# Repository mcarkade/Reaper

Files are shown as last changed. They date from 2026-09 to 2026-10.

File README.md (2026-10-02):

# Reaper

**Current shop jobs: [four smaller sequential DXFs](Plywood/Batches/README.md).** Cut those four OR the full master once, never both. Their part geometry is identical.
**[Open the complete R5G beginner assembly guide](Reaper_Beginner_Assembly_R5G.pdf).** Use its part atlas, illustrated fitting and assembly sequence, wiring, configuration and physical acceptance gates.

| Find | Current location |
|---|---|
| All 37 plywood pieces, one combined cutting file | [R5G DXF](Plywood/Reaper_ALL_PLYWOOD_R5G_6mm_PROVISIONAL.dxf) and [cutting instructions](Plywood/README.md) |
| Part quantities and stock-panel positions | [Parts.csv](Data/Parts.csv), [panel map](Plywood/PART_TO_PANEL.csv) |
| Missed unchanged A23/A36/HTRB STLs | [Print/Individual](Print/Individual), [print instructions](Print/README.md) |
| Current finished CAD and laser stock | [CAD](CAD), [wood fitting details](Data/Wood_Assembly_Datums.md) |
| Existing foam cutting files | [Foam](Foam) |
| Wiring and remaining acceptance checks | [Wiring](Illustrations/Complete_Wiring.svg), [physical checks](Data/Physical_Checks.csv) |

The current requested cutting set contains 37 nominal 6 mm plywood pieces including A26 and reinforced A44_L/R. A26 has no motor screw holes; verify the real motor and complete mount fit before hand marking/drilling. This cutting file includes A18's requested 0.5 mm total upper receiver allowance, strengthened A01 profiles and the shortened A62_A stock. A43 face rebates and A44 underside paring remain secondary operations shown in the guide; the laser cannot make them.

The geometry/layout is digitally checked. Actual stock thickness, kerf, printed receiver batch, physical insertion, screw engagement, adhesive quality and loaded performance remain qualification checks. The earlier R5F PDF, old wood jobs and printed A26/A44 fit prototypes are archived references; use the R5G guide and cutting set for the current job. Existing foam and unrelated prints are retained. Most parts are already printed; do not reprint them automatically.

Landing gear is deferred until after midsems; DARTS registration is pending. The 20%-chord CG is a geometric starting point. CAD or bench checks do not establish flight readiness.

[Original CAD model](https://cad.onshape.com/documents/da0c1a9f98b6358f736153b1/w/040544fbf77b8cf6608e2eb9/e/28c526eeb45b3f50fa69269f) Â· [Source build video](https://www.youtube.com/watch?v=X-Q08HQq7fM)

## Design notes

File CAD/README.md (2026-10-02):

# Current CAD

Reaper_R5_Assembly.step is the named R5G assembly: 66 original part identities plus two preserved whole carbon rods. Parts contains finished world-coordinate geometry; Stock_Blanks contains distinct laser stock; Secondary_Removal contains local finishing tools. A26 and A44 are current plywood parts. Earlier printed fit geometry is preserved in Archive_Fit_Prototypes, and obsolete secondary operations in Archive_Secondary_R5F.

Native assembled foil/skin IDs differ from the FW manufacturing-wrap IDs. N1 is an owned printed nose reference without a corresponding native part in this source set; no mapping is invented. Accepted source foam skins are unchanged reference geometry: the guide requires local internal relief against reinforced A44 and actual board thickness. Raw topology, a clean compound or a printable mesh does not prove physical fit, insertion, retention, material strength or flight readiness.

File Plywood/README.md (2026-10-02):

# Current plywood cutting job

**Current shop jobs: [four smaller sequential DXFs](Batches/README.md).** Cut all four once OR the full master once, never both. Their part geometry is identical.
[Reaper_ALL_PLYWOOD_R5G_6mm_PROVISIONAL.dxf](Reaper_ALL_PLYWOOD_R5G_6mm_PROVISIONAL.dxf) contains all 37 aircraft pieces, one of each listed ID, across two 609.6 Ã— 457.2 mm stock layouts. [Layout image](Maps/ALL_PLYWOOD_R5G_Layout.png), [part map](PART_TO_PANEL.csv) and [manufacturing map](Manufacturing_Map.json) identify the pieces. Individual DXFs are the same profiles used in the combined file, for reference; do not cut a second set.

Use nominal 6 mm plywood, millimetres, 100% scale and CUT only. Keep stock face grain along each panel's +X/long direction. A18 is intentionally rotated 90 degrees in this layout to carry its physical grain correctly. Reference stock borders and labels must not cut. Each layout is a separate stock sheet; panel 2 starts at X659.6 mm in the combined file. Nominal minimum part gap is 5 mm; geometric serialization differs by under 0.000004 mm. The shop must measure actual kerf, thickness and machine limits before cutting; no kerf offset is encoded.

All digital profiles and nominal extrusions passed independent readback, source-profile comparison, overlap/spacing, grain and quantity checks. Physical fit and strength are unverified. Qualify representative coupons and dry-fit the actual printed A12 receiver and wood interfaces before committing the complete cutting run.

A43 shallow seats, A62_F's A54 seat, spar seating relief and other existing source secondary operations do not come from laser through-cutting. Follow the guide and [wood datums](../Data/Wood_Assembly_Datums.md). A44's stock-only underside tail allowance must be pared to the finished profile, preserving its full tip and A53 bond area. [Reference paring profiles](Paring_Templates) are explicitly not laser jobs.

Old separate R5F panel files and maps in Archive_R5F are superseded. The current cutting entry is the single R5G combined DXF above.

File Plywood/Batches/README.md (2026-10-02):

# Four sequential cutting jobs

Cut batches01,02,03,04 once each: 9+9+9+10=37 complete pieces. They are translation-only derivatives of the unchanged full R5G master; no part is cropped, rotated or rescaled. All81 closed CUT contours are preserved exactly once. Do not also cut the full master or individual profiles.

Each nominal stock layout is609.6 x228.6mm, grain along X, with10mm margins and5mm part gaps. Cut in millimetres at100%scale, CUT only; reference borders and labels do not cut. These four half-panel layouts occupy the same total stock area as the two original609.6 x457.2mm sheets, before real handling/kerf considerations. Keep material grain and safe stock support. The shop must confirm actual bed size, stock thickness and kerf coupon. Largest individual part A13 is550.6602 x95.64445mm and remains intact; do not scale it to fit a smaller machine.

PART_TO_BATCH.csv and FOUR_BATCHES_Layout.png identify each batch. BATCH_MAP.json records unchanged-master identity and exact translations. The full combined file in the parent directory remains a reference/alternative layout. Guide instructions and secondary fitting are unchanged, including A43 shallow rebates, A44 tail underside paring and A26 physical mount fit/manual motor drilling.

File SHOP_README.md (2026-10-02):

# Workshop files

**Current shop jobs: [four smaller sequential DXFs](Plywood/Batches/README.md).** Cut those four OR the full master once, never both. Their part geometry is identical.
Use the [R5G complete guide](Reaper_Beginner_Assembly_R5G.pdf), [part list](Data/Parts.csv) and [current combined plywood DXF](Plywood/Reaper_ALL_PLYWOOD_R5G_6mm_PROVISIONAL.dxf). All 37 plywood quantities are included across two stock layouts in one file. The older panel jobs in Plywood/Archive_R5F are superseded references.

Measure actual plywood thickness and laser kerf and qualify mating coupons before the full job. Nominal stock is 6 mm, each stock layout is 609.6 Ã— 457.2 mm, and its long X direction is the required face-grain direction. Use millimetres, 100% scale, CUT only. Disable REFERENCE_NOT_CUT and LABELS_NOT_CUT. Select one stock layout at a time unless the bed accepts both; the file spans 1269.2 mm and does not represent one physical sheet. No kerf compensation is encoded.

A18 already includes 0.25 mm per opposed upper receiver-facing edge; do not add that allowance again. Stock remains 6 mm. A43 keeps full-thickness surrounding material and requires only the illustrated local face rebates. A44 stock includes a 3 mm underside tail web: pare the exact sacrificial allowance to the finished taper without shortening the tip before bonding A53. The old A44 trailing-tip trim is superseded. A26 has no motor screw holes and needs real-hardware marking after the physical frame dry-fit. A62_A's old 13.015 mm aft trim is incorporated into the cut length; do not repeat it.

The missed unchanged prints are A23, A36 and HTRB, one each. Use [Print/README.md](Print/README.md); PLA is available, while the source reference recipes specify PLA+. Neither a filename nor a slicer recipe establishes loaded strength. Preserve already completed unrelated prints and foam. Landing-gear hardware remains a later stage.

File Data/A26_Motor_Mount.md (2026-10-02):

# A26 motor mount

Current R5G is nominal 6 mm plywood with no motor screw holes, as requested for actual-motor hand marking. The shaft relief and source axis at X0/Z-2.5 mm are retained; nominal keel/side receiving regions are 6 mm. A26 is included in the single combined plywood file. The earlier square-pattern plate and printed fit prototypes are superseded references.

The documented motor is EMAX ECO II 2807 1300KV. Its [manufacturer drawing](EMAX_ECOII_2807_Manufacturer_Drawing.jpg) specifies four M3 mounting holes on a 19 mm diameter bolt circle: adjacent centres are 13.435 mm, not a 19 mm square. Align the real motor and mark the pattern only after the complete A26/A43/A62_A/printed-tail dry-fit proves seating, assembly order and tool access. The current DXF deliberately has zero motor screw holes; the centre shaft relief is not a mounting hole.

The frame joint is chiefly the forward-face bond and keel seat; do not mistake the plate's flank recesses for fully captured load-bearing tongues. Proof the real attachment and load path. Digital installed interference and sampled aft insertion checks passed, while a vertical drop is blocked. They do not establish the actual plywood fit or bonding strength. User-reported incorrect physical frame fit remains a physical acceptance gate until this exact replacement is dry-fitted.

A62_A's current stock length is 482.650 mm, flush at Y582.650. Its old 13.015 mm aft projection has already been removed in the current cutting profile: do not trim a further 13.015 mm.

Choose motor screws from the actual plate/washer stack and measured safe thread depth. EMAX supplies M3×8/M3×10 screws, but their nominal protrusions through a 6 mm plate are not proof of adequate engagement or winding clearance. Confirm seating, shaft/boss clearance, screw bottoming, head support, real driver approach, wiring and later service access. The actual hardware-length checks, loaded thrust/torque joint tests and propulsion thermal/vibration tests have not been performed. Do not run a propeller until physical retention and the guide's safety gates pass.

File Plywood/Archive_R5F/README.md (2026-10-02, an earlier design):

Superseded R5F wood panel/coupon jobs and maps. Current37-piece cutting uses the four jobs in ../Batches or the unchanged ../Reaper_ALL_PLYWOOD_R5G_6mm_PROVISIONAL.dxf master once, never both. These archived jobs are not current manufacturing instructions.

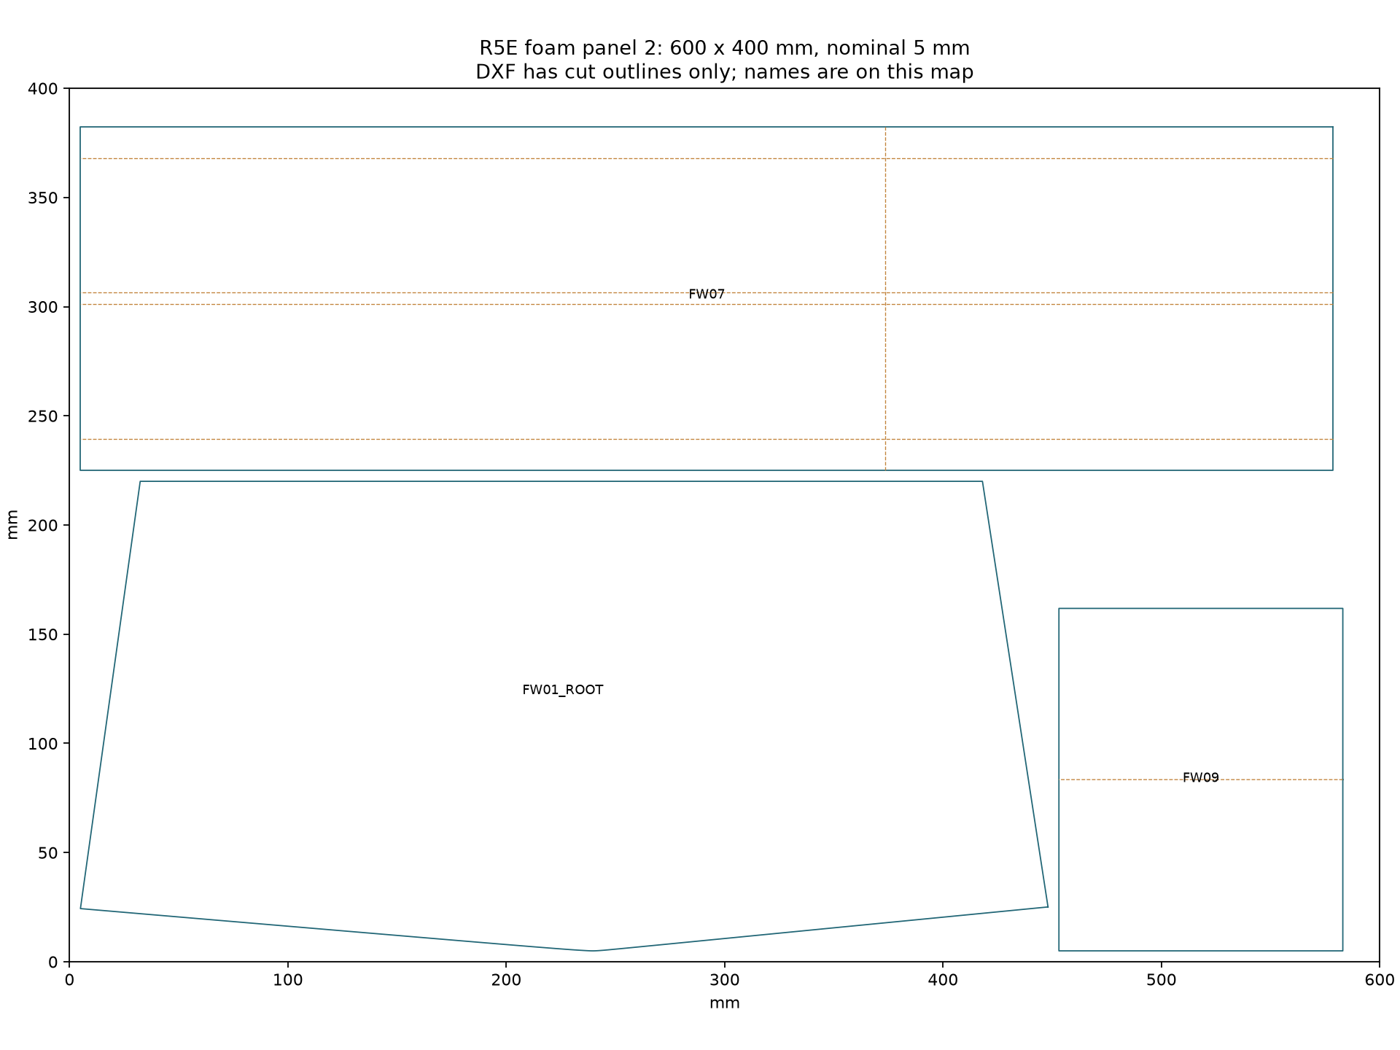
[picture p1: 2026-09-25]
Foam/Maps/REAPER_R5E_FOAM_400x600_PANEL_02.png

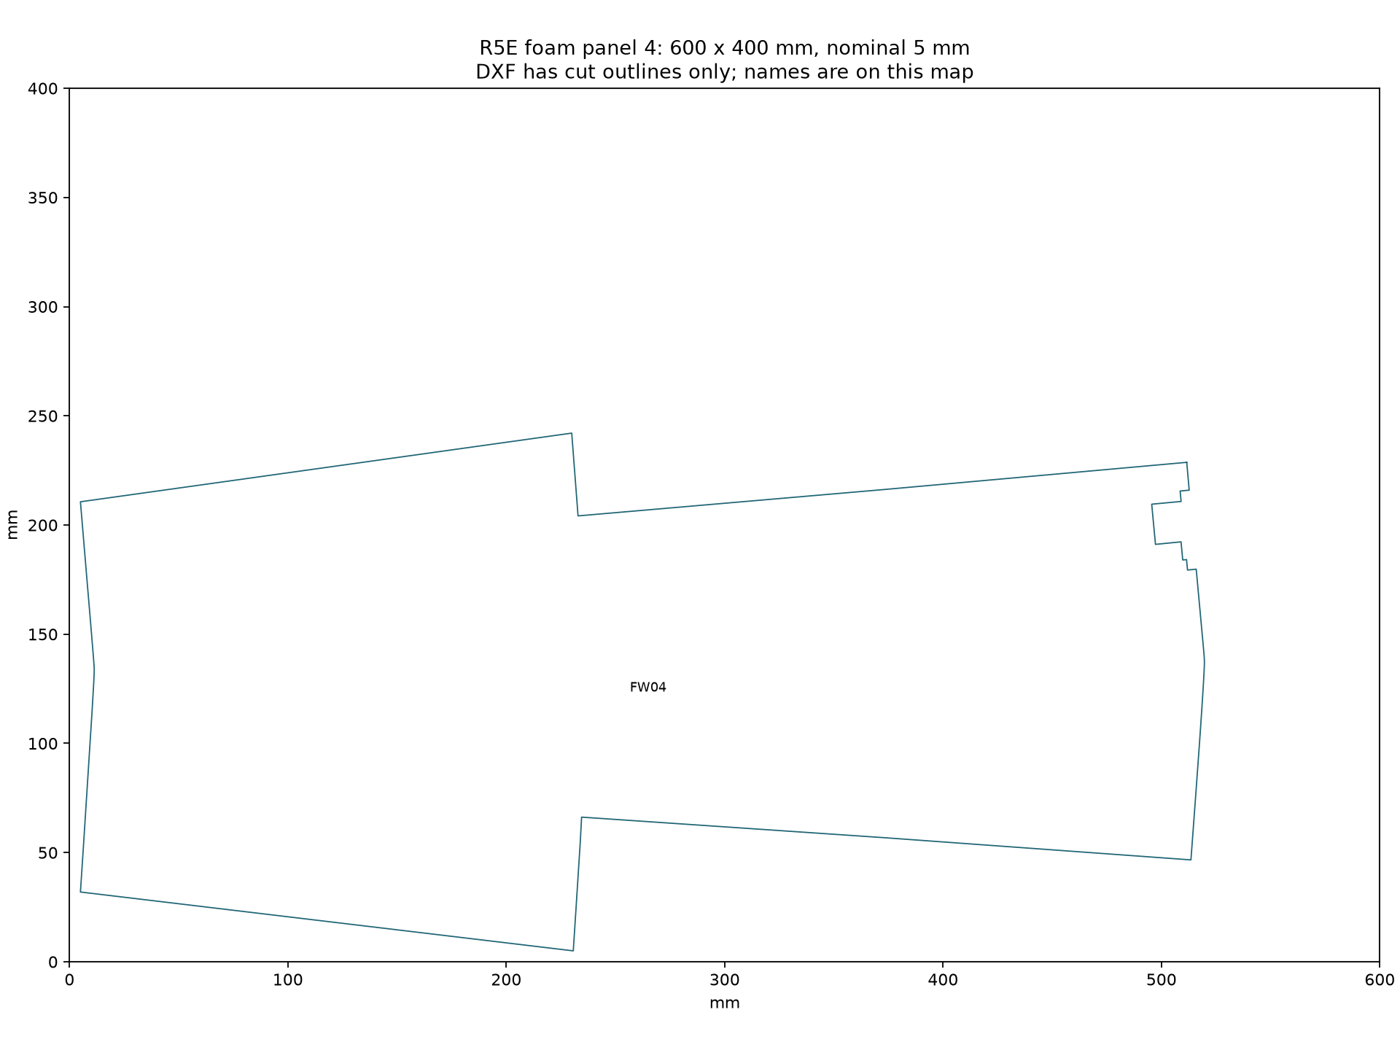
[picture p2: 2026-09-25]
Foam/Maps/REAPER_R5E_FOAM_400x600_PANEL_04.png

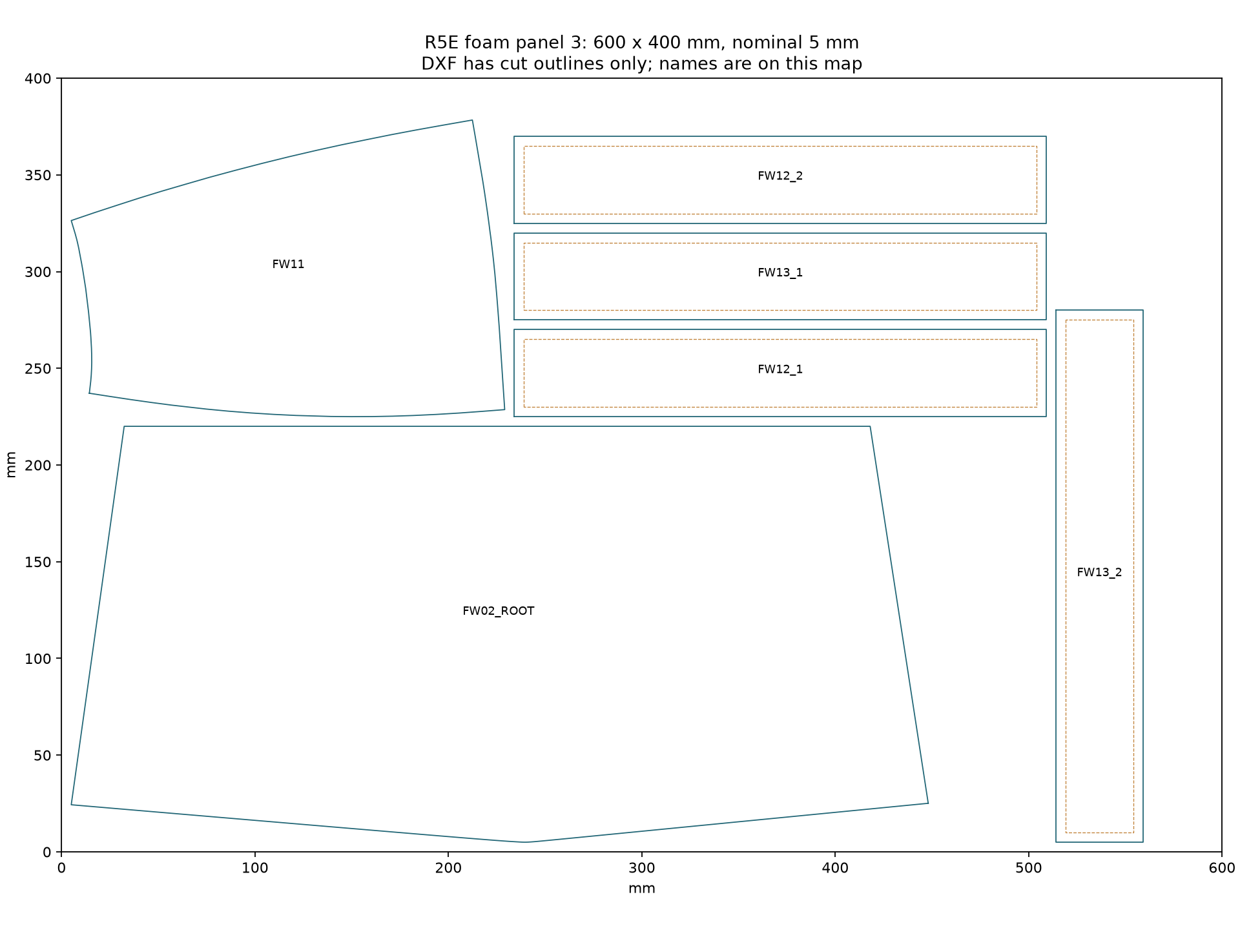
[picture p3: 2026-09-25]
Foam/Maps/REAPER_R5E_FOAM_400x600_PANEL_03.png

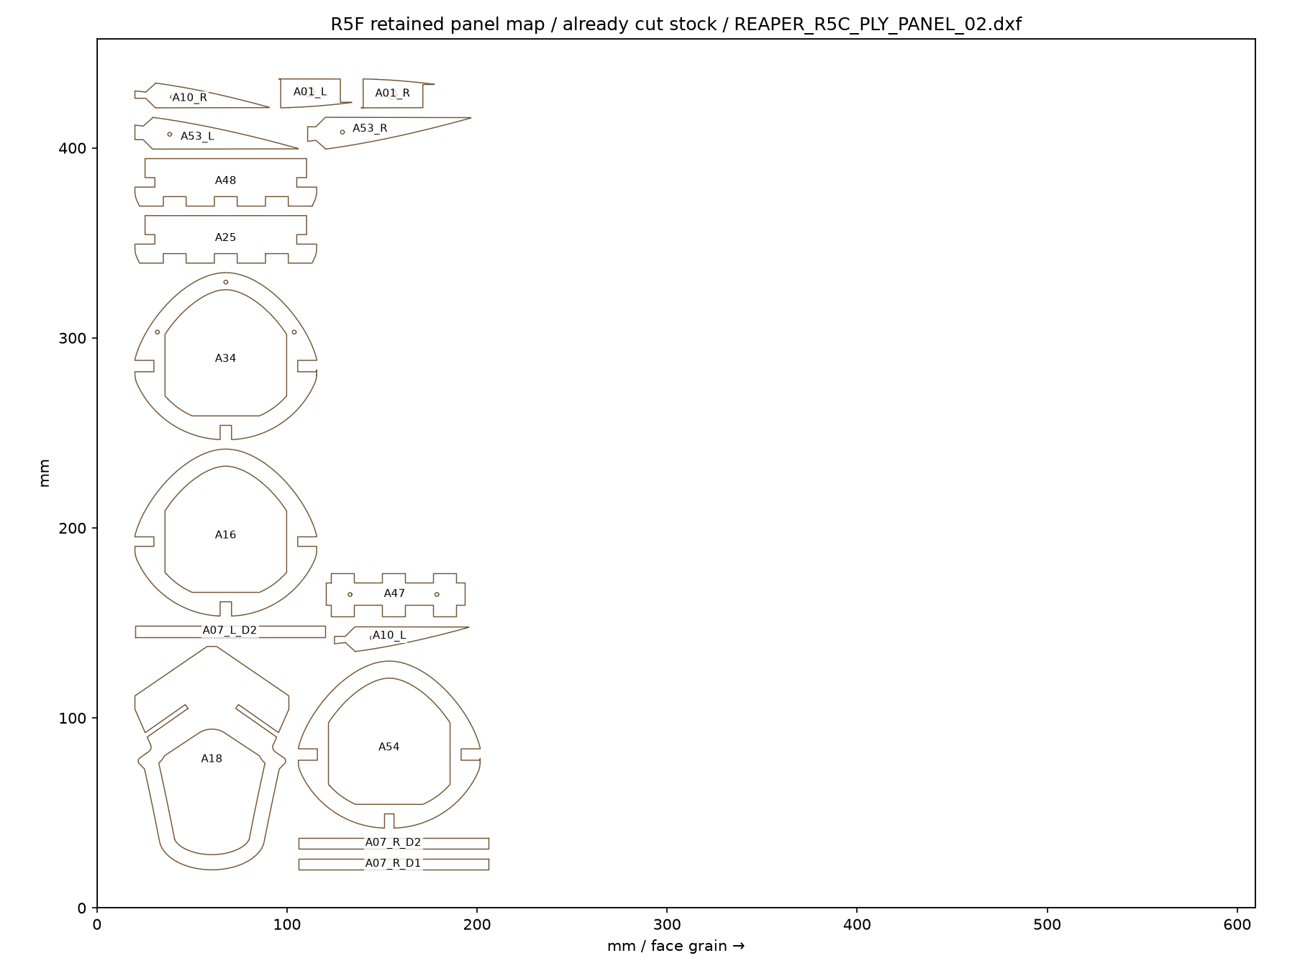
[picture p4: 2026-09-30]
Plywood/Maps/REAPER_R5C_PLY_PANEL_02.png

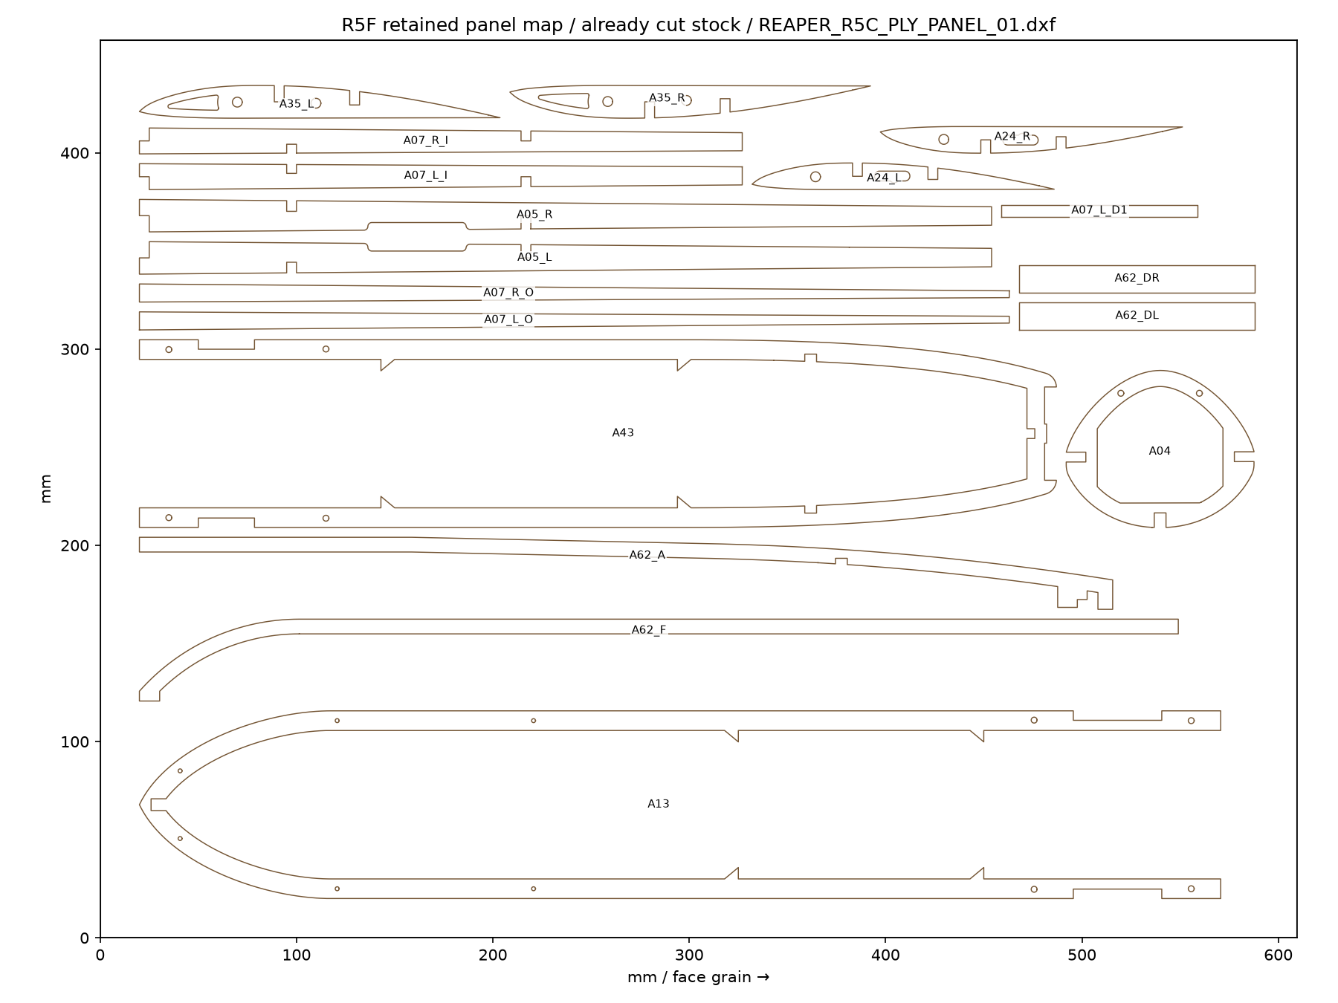
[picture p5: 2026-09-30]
Plywood/Maps/REAPER_R5C_PLY_PANEL_01.png

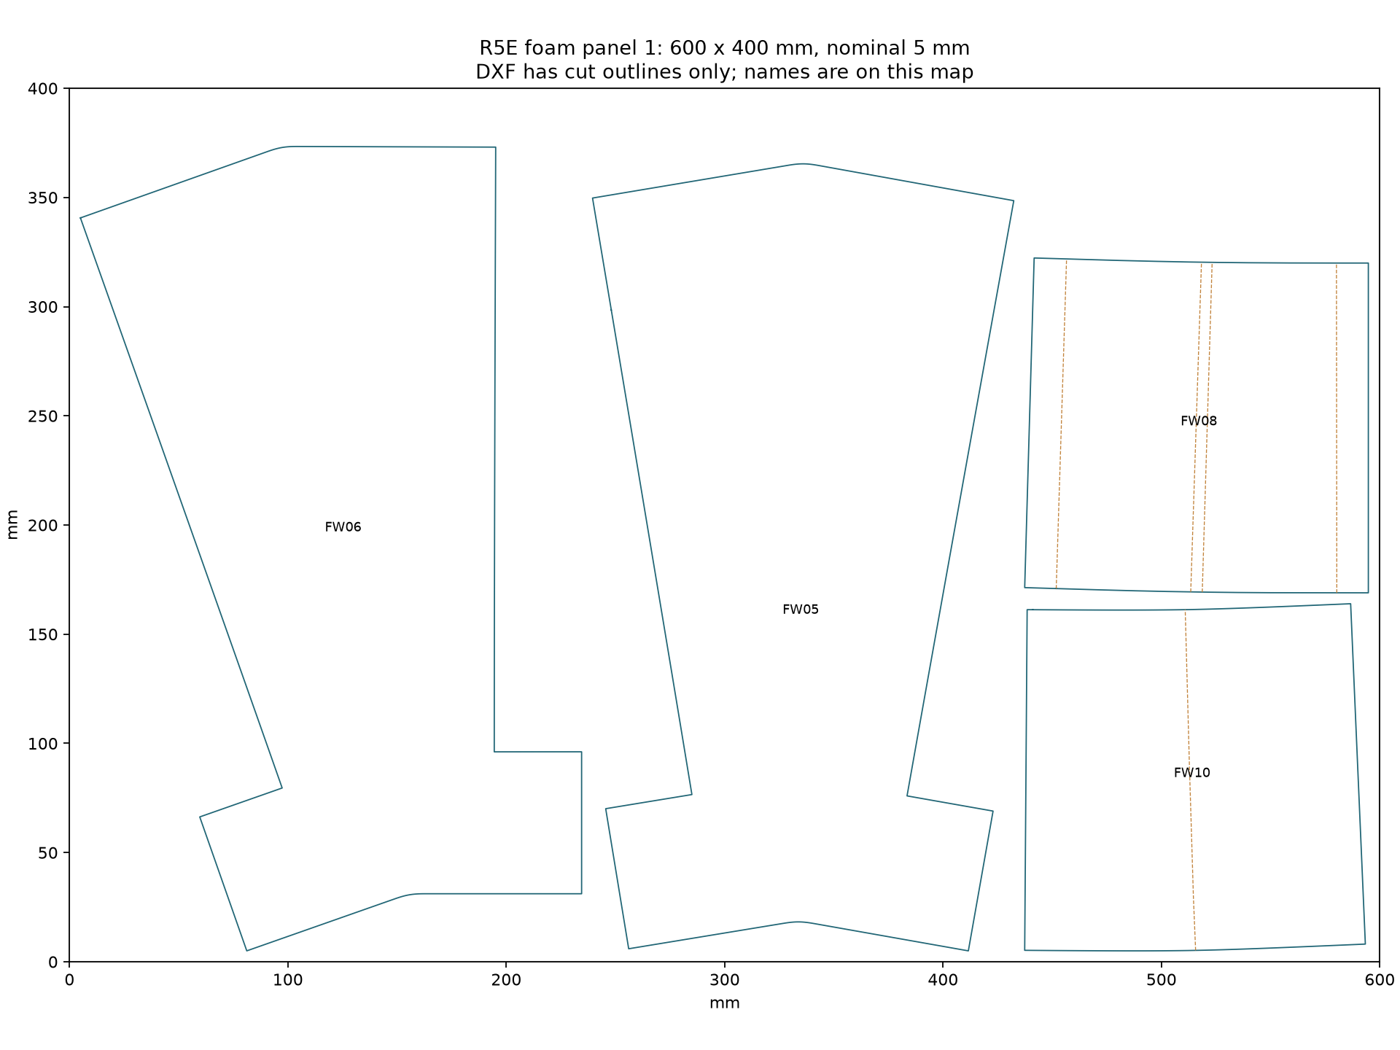
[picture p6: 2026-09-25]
Foam/Maps/REAPER_R5E_FOAM_400x600_PANEL_01.png

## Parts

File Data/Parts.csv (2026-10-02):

id | name | material | quantity | make | file
A04 | Rear body former | nominal 6 mm plywood; actual stock unmeasured | 1 | laser stock; listed secondary finishing and physical dry-fit required | Plywood/Reaper_ALL_PLYWOOD_R5G_6mm_PROVISIONAL.dxf
A13 | Front horizontal fuselage frame | nominal 6 mm plywood; actual stock unmeasured | 1 | laser stock; listed secondary finishing and physical dry-fit required | Plywood/Reaper_ALL_PLYWOOD_R5G_6mm_PROVISIONAL.dxf
A16 | Body former at Y233.65mm | nominal 6 mm plywood; actual stock unmeasured | 1 | laser stock; listed secondary finishing and physical dry-fit required | Plywood/Reaper_ALL_PLYWOOD_R5G_6mm_PROVISIONAL.dxf
A18 | Tail-carrier bulkhead | nominal 6 mm plywood; actual stock unmeasured | 1 | laser stock; listed secondary finishing and physical dry-fit required | Plywood/Reaper_ALL_PLYWOOD_R5G_6mm_PROVISIONAL.dxf
A25 | Forward main-gear crossmember | nominal 6 mm plywood; actual stock unmeasured | 1 | laser stock; listed secondary finishing and physical dry-fit required | Plywood/Reaper_ALL_PLYWOOD_R5G_6mm_PROVISIONAL.dxf
A26 | Motor firewall; no motor screw holes | nominal 6 mm plywood; actual stock unmeasured | 1 | laser stock; listed secondary finishing and physical dry-fit required | Plywood/Reaper_ALL_PLYWOOD_R5G_6mm_PROVISIONAL.dxf
A34 | Front body former at Y-130mm | nominal 6 mm plywood; actual stock unmeasured | 1 | laser stock; listed secondary finishing and physical dry-fit required | Plywood/Reaper_ALL_PLYWOOD_R5G_6mm_PROVISIONAL.dxf
A43 | Aft horizontal fuselage frame | nominal 6 mm plywood; actual stock unmeasured | 1 | laser stock; listed secondary finishing and physical dry-fit required | Plywood/Reaper_ALL_PLYWOOD_R5G_6mm_PROVISIONAL.dxf
A47 | Main-gear crossplate | nominal 6 mm plywood; actual stock unmeasured | 1 | laser stock; listed secondary finishing and physical dry-fit required | Plywood/Reaper_ALL_PLYWOOD_R5G_6mm_PROVISIONAL.dxf
A48 | Aft main-gear crossmember | nominal 6 mm plywood; actual stock unmeasured | 1 | laser stock; listed secondary finishing and physical dry-fit required | Plywood/Reaper_ALL_PLYWOOD_R5G_6mm_PROVISIONAL.dxf
A54 | Body former at Y-5mm | nominal 6 mm plywood; actual stock unmeasured | 1 | laser stock; listed secondary finishing and physical dry-fit required | Plywood/Reaper_ALL_PLYWOOD_R5G_6mm_PROVISIONAL.dxf
A01_R | Rear-rod support rib at span130mm - right | nominal 6 mm plywood; actual stock unmeasured | 1 | laser stock; listed secondary finishing and physical dry-fit required | Plywood/Reaper_ALL_PLYWOOD_R5G_6mm_PROVISIONAL.dxf
A01_L | Rear-rod support rib at span130mm - left | nominal 6 mm plywood; actual stock unmeasured | 1 | laser stock; listed secondary finishing and physical dry-fit required | Plywood/Reaper_ALL_PLYWOOD_R5G_6mm_PROVISIONAL.dxf
A05_R | Front wing spar - right | nominal 6 mm plywood; actual stock unmeasured | 1 | laser stock; listed secondary finishing and physical dry-fit required | Plywood/Reaper_ALL_PLYWOOD_R5G_6mm_PROVISIONAL.dxf
A05_L | Front wing spar - left | nominal 6 mm plywood; actual stock unmeasured | 1 | laser stock; listed secondary finishing and physical dry-fit required | Plywood/Reaper_ALL_PLYWOOD_R5G_6mm_PROVISIONAL.dxf
A10_R | Outer aileron endplate - right | nominal 6 mm plywood; actual stock unmeasured | 1 | laser stock; listed secondary finishing and physical dry-fit required | Plywood/Reaper_ALL_PLYWOOD_R5G_6mm_PROVISIONAL.dxf
A10_L | Outer aileron endplate - left | nominal 6 mm plywood; actual stock unmeasured | 1 | laser stock; listed secondary finishing and physical dry-fit required | Plywood/Reaper_ALL_PLYWOOD_R5G_6mm_PROVISIONAL.dxf
A24_R | Middle wing rib at span250mm - right | nominal 6 mm plywood; actual stock unmeasured | 1 | laser stock; listed secondary finishing and physical dry-fit required | Plywood/Reaper_ALL_PLYWOOD_R5G_6mm_PROVISIONAL.dxf
A24_L | Middle wing rib at span250mm - left | nominal 6 mm plywood; actual stock unmeasured | 1 | laser stock; listed secondary finishing and physical dry-fit required | Plywood/Reaper_ALL_PLYWOOD_R5G_6mm_PROVISIONAL.dxf
A35_R | Inner wing rib at span53mm - right | nominal 6 mm plywood; actual stock unmeasured | 1 | laser stock; listed secondary finishing and physical dry-fit required | Plywood/Reaper_ALL_PLYWOOD_R5G_6mm_PROVISIONAL.dxf
A35_L | Inner wing rib at span53mm - left | nominal 6 mm plywood; actual stock unmeasured | 1 | laser stock; listed secondary finishing and physical dry-fit required | Plywood/Reaper_ALL_PLYWOOD_R5G_6mm_PROVISIONAL.dxf
A44_R | Right reinforced outer wing rib; pare underside tail allowance | nominal 6 mm plywood; actual stock unmeasured | 1 | laser stock; listed secondary finishing and physical dry-fit required | Plywood/Reaper_ALL_PLYWOOD_R5G_6mm_PROVISIONAL.dxf
A44_L | Left reinforced outer wing rib; pare underside tail allowance | nominal 6 mm plywood; actual stock unmeasured | 1 | laser stock; listed secondary finishing and physical dry-fit required | Plywood/Reaper_ALL_PLYWOOD_R5G_6mm_PROVISIONAL.dxf
A53_R | Inner aileron endplate - right | nominal 6 mm plywood; actual stock unmeasured | 1 | laser stock; listed secondary finishing and physical dry-fit required | Plywood/Reaper_ALL_PLYWOOD_R5G_6mm_PROVISIONAL.dxf
A53_L | Inner aileron endplate - left | nominal 6 mm plywood; actual stock unmeasured | 1 | laser stock; listed secondary finishing and physical dry-fit required | Plywood/Reaper_ALL_PLYWOOD_R5G_6mm_PROVISIONAL.dxf
A62_F | Lower fuselage keel - front half | nominal 6 mm plywood; actual stock unmeasured | 1 | laser stock; listed secondary finishing and physical dry-fit required | Plywood/Reaper_ALL_PLYWOOD_R5G_6mm_PROVISIONAL.dxf
A62_A | Lower fuselage keel - aft half | nominal 6 mm plywood; actual stock unmeasured | 1 | laser stock; listed secondary finishing and physical dry-fit required | Plywood/Reaper_ALL_PLYWOOD_R5G_6mm_PROVISIONAL.dxf
A62_DL | Keel joint - left side lap | nominal 6 mm plywood; actual stock unmeasured | 1 | laser stock; listed secondary finishing and physical dry-fit required | Plywood/Reaper_ALL_PLYWOOD_R5G_6mm_PROVISIONAL.dxf
A62_DR | Keel joint - right side lap | nominal 6 mm plywood; actual stock unmeasured | 1 | laser stock; listed secondary finishing and physical dry-fit required | Plywood/Reaper_ALL_PLYWOOD_R5G_6mm_PROVISIONAL.dxf
A07_R_I | Rear wing spar - right inboard section | nominal 6 mm plywood; actual stock unmeasured | 1 | laser stock; listed secondary finishing and physical dry-fit required | Plywood/Reaper_ALL_PLYWOOD_R5G_6mm_PROVISIONAL.dxf
A07_R_O | Rear wing spar - right outboard section | nominal 6 mm plywood; actual stock unmeasured | 1 | laser stock; listed secondary finishing and physical dry-fit required | Plywood/Reaper_ALL_PLYWOOD_R5G_6mm_PROVISIONAL.dxf
A07_R_D1 | Rear wing spar - right first face lap | nominal 6 mm plywood; actual stock unmeasured | 1 | laser stock; listed secondary finishing and physical dry-fit required | Plywood/Reaper_ALL_PLYWOOD_R5G_6mm_PROVISIONAL.dxf
A07_R_D2 | Rear wing spar - right second face lap | nominal 6 mm plywood; actual stock unmeasured | 1 | laser stock; listed secondary finishing and physical dry-fit required | Plywood/Reaper_ALL_PLYWOOD_R5G_6mm_PROVISIONAL.dxf
A07_L_I | Rear wing spar - left inboard section | nominal 6 mm plywood; actual stock unmeasured | 1 | laser stock; listed secondary finishing and physical dry-fit required | Plywood/Reaper_ALL_PLYWOOD_R5G_6mm_PROVISIONAL.dxf
A07_L_O | Rear wing spar - left outboard section | nominal 6 mm plywood; actual stock unmeasured | 1 | laser stock; listed secondary finishing and physical dry-fit required | Plywood/Reaper_ALL_PLYWOOD_R5G_6mm_PROVISIONAL.dxf
A07_L_D1 | Rear wing spar - left first face lap | nominal 6 mm plywood; actual stock unmeasured | 1 | laser stock; listed secondary finishing and physical dry-fit required | Plywood/Reaper_ALL_PLYWOOD_R5G_6mm_PROVISIONAL.dxf
A07_L_D2 | Rear wing spar - left second face lap | nominal 6 mm plywood; actual stock unmeasured | 1 | laser stock; listed secondary finishing and physical dry-fit required | Plywood/Reaper_ALL_PLYWOOD_R5G_6mm_PROVISIONAL.dxf
FW01_ROOT | left_inner_wing root | 5 mm foamboard | 1 | laser panel; join matching ROOT/TIP straight edges with foam-safe glue and outer-paper tape | Foam/REAPER_R5E_FOAM_400x600_PANEL_02.dxf
FW01_TIP | left_inner_wing tip | 5 mm foamboard | 1 | laser panel; join matching ROOT/TIP straight edges with foam-safe glue and outer-paper tape | Foam/REAPER_R5E_FOAM_400x600_PANEL_06.dxf
FW02_ROOT | right_inner_wing root | 5 mm foamboard | 1 | laser panel; join matching ROOT/TIP straight edges with foam-safe glue and outer-paper tape | Foam/REAPER_R5E_FOAM_400x600_PANEL_03.dxf
FW02_TIP | right_inner_wing tip | 5 mm foamboard | 1 | laser panel; join matching ROOT/TIP straight edges with foam-safe glue and outer-paper tape | Foam/REAPER_R5E_FOAM_400x600_PANEL_06.dxf
FW03 | right_outer_wing | 5 mm foamboard | 1 | laser panel; hand form/trim | Foam/REAPER_R5E_FOAM_400x600_PANEL_05.dxf
FW04 | left_outer_wing | 5 mm foamboard | 1 | laser panel; hand form/trim | Foam/REAPER_R5E_FOAM_400x600_PANEL_04.dxf
FW05 | right_fixed_tail | 5 mm foamboard | 1 | laser panel; hand form/trim | Foam/REAPER_R5E_FOAM_400x600_PANEL_01.dxf
FW06 | left_fixed_tail | 5 mm foamboard | 1 | laser panel; hand form/trim | Foam/REAPER_R5E_FOAM_400x600_PANEL_01.dxf
FW07 | lower_body_wrap | 5 mm foamboard | 1 | laser panel; hand form/trim | Foam/REAPER_R5E_FOAM_400x600_PANEL_02.dxf
FW08 | aft_lower_body | 5 mm foamboard | 1 | laser panel; hand form/trim | Foam/REAPER_R5E_FOAM_400x600_PANEL_01.dxf
FW09 | front_upper_cover | 5 mm foamboard | 1 | laser panel; hand form/trim | Foam/REAPER_R5E_FOAM_400x600_PANEL_02.dxf
FW10 | rear_upper_cover | 5 mm foamboard | 1 | laser panel; hand form/trim | Foam/REAPER_R5E_FOAM_400x600_PANEL_01.dxf
FW11 | tail_underside | 5 mm foamboard | 1 | laser panel; hand form/trim | Foam/REAPER_R5E_FOAM_400x600_PANEL_03.dxf
FW12 | right_moving_tail | 5 mm foamboard | 2 | laser panel; hand form/trim | Foam/REAPER_R5E_FOAM_400x600_PANEL_03.dxf
FW13 | left_moving_tail | 5 mm foamboard | 2 | laser panel; hand form/trim | Foam/REAPER_R5E_FOAM_400x600_PANEL_03.dxf
A06 | Centre fairing | PLA+ | 1 | print | Print/Individual/A06_2W_10GYR_SUP_L0p2_B8.stl
A11 | Left printed aileron | PLA+ | 1 | print | Print/Individual/A11_2W_10GYR_SUP_L0p2_B8.stl
A12 | Tail carrier | PLA+ | 1 | reuse after dry fit if already printed; otherwise print | Print/Individual/A12_2W_15GYR_SUP_L0p2_B8.stl
A21 | Right printed aileron | PLA+ | 1 | print | Print/Individual/A21_2W_10GYR_SUP_L0p2_B8.stl
A23 | Left fixed aileron hinge rail | PLA+ | 1 | print | Print/Individual/A23_3W_15GYR_NOSUP_L0p2_B8.stl
A36 | Right fixed aileron hinge rail | PLA+ | 1 | print | Print/Individual/A36_3W_15GYR_NOSUP_L0p2_B8.stl
A45 | Right wing root | PLA+ | 1 | print | Print/Individual/A45_4W_35GYR_NOSUP_L0p2_B8.stl
A55 | Left wing root | PLA+ | 1 | print | Print/Individual/A55_4W_35GYR_NOSUP_L0p2_B8.stl
N1 | Owned nose already printed | PLA+ | 1 | reuse; do not print again | Print/N1_Reference_Already_Printed.stl
HWR | Right aileron horn | PLA+ | 1 | print | Print/Individual/HWR_3W_100RECT_NOSUP_L0p2_B5.stl
HWL | Left aileron horn | PLA+ | 1 | print | Print/Individual/HWL_3W_100RECT_NOSUP_L0p2_B5.stl
HTR | Right tail horn with base | PLA+ | 1 | print | Print/Individual/HTR_3W_100RECT_SUP_L0p2_B5.stl
HTL | Left tail horn with base | PLA+ | 1 | print | Print/Individual/HTL_3W_100RECT_SUP_L0p2_B5.stl
HTRB | Right tail horn backing plate | PLA+ | 1 | print | Print/Individual/HTRB_3W_100RECT_NOSUP_L0p2_B5.stl
HTLB | Left tail horn backing plate | PLA+ | 1 | print | Print/Individual/HTLB_3W_100RECT_NOSUP_L0p2_B5.stl

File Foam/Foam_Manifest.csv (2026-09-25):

pattern | label | quantity | nominal_board_mm | source_ids | replaces | dxf | cut_bbox_mm | area_mm2 | notes | max_edge_strain_percent
FW01 | left_inner_wing | 2 | 5 | ['A52'] | ['F01'] | FW01_left_inner_wing.dxf | [443.05563, 455.62468] | 167058.9714844628 | One folded skin. Keep outer paper continuous; dry-form around original ribs and spars. ROOT/TIP/LEADING EDGE labels register the original 3D surface and are not cuts. Cut ROOT and TIP separately on 600 x 400 mm beds; join the straight edges before forming.
FW02 | right_inner_wing | 2 | 5 | ['A49'] | ['F02'] | FW02_right_inner_wing.dxf | [443.05481, 455.62433] | 167058.84805733734 | One folded skin. Keep outer paper continuous; dry-form around original ribs and spars. ROOT/TIP/LEADING EDGE labels register the original 3D surface and are not cuts. Cut ROOT and TIP separately on 600 x 400 mm beds; join the straight edges before forming.
FW03 | right_outer_wing | 1 | 5 | ['A38'] | ['F03'] | FW03_right_outer_wing.dxf | [237.07398, 514.67685] | 91701.70903098777 | One folded skin. Keep outer paper continuous; dry-form around original ribs and spars. ROOT/TIP/LEADING EDGE labels register the original 3D surface and are not cuts.
FW04 | left_outer_wing | 1 | 5 | ['A27'] | ['F04'] | FW04_left_outer_wing.dxf | [237.07398, 514.67566] | 91701.72786860388 | One folded skin. Keep outer paper continuous; dry-form around original ribs and spars. ROOT/TIP/LEADING EDGE labels register the original 3D surface and are not cuts.
FW05 | right_fixed_tail | 1 | 5 | ['A57'] | ['F05', 'F07'] | FW05_right_fixed_tail.dxf | [192.8899889145026, 360.3790901105466] | 51897.9239956293 | Single full tail skin including root collar. No separate collar strip. | 0.17362791394773813
FW06 | left_fixed_tail | 1 | 5 | ['A22'] | ['F06', 'F08'] | FW06_left_fixed_tail.dxf | [229.49472966254697, 368.33071610834344] | 51897.799036495 | Single full tail skin including root collar. No separate collar strip. | 0.1736753066119867
FW07 | lower_body_wrap | 1 | 5 | ['A56', 'A17'] | ['F13', 'F09', 'F14', 'F10', 'F15', 'F16', 'F12', 'F18', 'F11', 'F17'] | FW07_lower_body_wrap.dxf | [157.42382239683042, 573.65] | 90306.17571794176 | One continuous wrap for front and middle lower body. Longitudinal marks locate gentle changes in curvature; NOT seams or laser cuts. Cross-line at205mm is a station mark only. Remove inner paper and precurve; preserve outer paper. | 0
FW08 | aft_lower_body | 1 | 5 | ['A42'] | ['F19', 'F20', 'F33', 'F21', 'F22'] | FW08_aft_lower_body.dxf | [157.3584902280108, 153.32042637786793] | 23441.431309836073 | One formed wrap; inner relief at marked transitions. Maximum joining registration mismatch 0.004mm; dry-fit and trim perimeter before glue.
FW09 | front_upper_cover | 1 | 5 | ['A08'] | ['F25', 'F26'] | FW09_front_upper_cover.dxf | [156.80822940601126, 130.00138993061893] | 20384.64567091041 | One formed wrap; inner relief at marked transitions. Maximum joining registration mismatch 0.001mm; dry-fit and trim perimeter before glue.
FW10 | rear_upper_cover | 1 | 5 | ['A15'] | ['F23', 'F24'] | FW10_rear_upper_cover.dxf | [155.9851097851031, 158.94707841873375] | 23735.456017216053 | One formed wrap; inner relief at marked transitions. Maximum joining registration mismatch 0.037mm; dry-fit and trim perimeter before glue.
FW11 | tail_underside | 1 | 5 | ['A20'] | ['F27', 'F28', 'F29', 'F30'] | FW11_tail_underside.dxf | [153.34808295499772, 224.09549953892068] | 27187.11156897397 | One compound-curved trial blank. Peel inner paper, gently preform and trim at frame. Full development is approximate: max1.315% local edge strain,99th percentile0.467%. If it buckles, make short overlapping darts from perimeter while keeping one connected blank; tape outer seam. Trial in paper first; do not force onto frame. | 1.3145643372712845
FW12 | right_moving_tail | 2 | 5 | ['A41'] | ['F31'] | FW12_right_moving_tail.dxf | [45.0, 275.03561] | 12376.60245 | Two 5 mm layers make one 10 mm control. Cut outline includes 5 mm trim allowance; laminate then carve rounded leading edge and trim to reference. Tape hinge at original axis.
FW13 | left_moving_tail | 2 | 5 | ['A60'] | ['F32'] | FW13_left_moving_tail.dxf | [45.0, 275.03561] | 12376.60245 | Two 5 mm layers make one 10 mm control. Cut outline includes 5 mm trim allowance; laminate then carve rounded leading edge and trim to reference. Tape hinge at original axis.

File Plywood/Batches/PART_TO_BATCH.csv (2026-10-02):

id | quantity | batch | translation_from_master_x_mm | translation_from_master_y_mm
A13 | 1 | Reaper_PLY_R5G_BATCH_01_OF_04_6mm_PROVISIONAL.dxf | -10.0 | -10.0
A07_L_I | 1 | Reaper_PLY_R5G_BATCH_01_OF_04_6mm_PROVISIONAL.dxf | -10.0 | -270.579381062984
A16 | 1 | Reaper_PLY_R5G_BATCH_01_OF_04_6mm_PROVISIONAL.dxf | -357.600021282008 | -42.94589106298399
A24_R | 1 | Reaper_PLY_R5G_BATCH_01_OF_04_6mm_PROVISIONAL.dxf | 25.318047654996008 | -289.142051062984
A48 | 1 | Reaper_PLY_R5G_BATCH_01_OF_04_6mm_PROVISIONAL.dxf | -669.6 | -240.51103923152652
A47 | 1 | Reaper_PLY_R5G_BATCH_01_OF_04_6mm_PROVISIONAL.dxf | -669.600001062986 | -24.750979231526486
A07_L_D2 | 1 | Reaper_PLY_R5G_BATCH_01_OF_04_6mm_PROVISIONAL.dxf | -491.2111601097671 | -13.750979231526486
A10_R | 1 | Reaper_PLY_R5G_BATCH_01_OF_04_6mm_PROVISIONAL.dxf | -256.95557234500404 | -291.8690839141467
A01_L | 1 | Reaper_PLY_R5G_BATCH_01_OF_04_6mm_PROVISIONAL.dxf | -189.64513009590007 | -411.07620000000003
A43 | 1 | Reaper_PLY_R5G_BATCH_02_OF_04_6mm_PROVISIONAL.dxf | -10.0 | -199.07232
A07_R_I | 1 | Reaper_PLY_R5G_BATCH_02_OF_04_6mm_PROVISIONAL.dxf | -10.0 | -288.774291062985
A18 | 1 | Reaper_PLY_R5G_BATCH_02_OF_04_6mm_PROVISIONAL.dxf | -197.60756671848276 | -10.0
A35_L | 1 | Reaper_PLY_R5G_BATCH_02_OF_04_6mm_PROVISIONAL.dxf | 301.9999787179921 | -306.969201062985
A44_L | 1 | Reaper_PLY_R5G_BATCH_02_OF_04_6mm_PROVISIONAL.dxf | -387.32638 | -289.50980923152787
A62_DL | 1 | Reaper_PLY_R5G_BATCH_02_OF_04_6mm_PROVISIONAL.dxf | -339.6060974873672 | -180.8774092315278
A07_L_D1 | 1 | Reaper_PLY_R5G_BATCH_02_OF_04_6mm_PROVISIONAL.dxf | 22.992433281517265 | -271.34955
A07_R_D2 | 1 | Reaper_PLY_R5G_BATCH_02_OF_04_6mm_PROVISIONAL.dxf | -631.8505264243713 | 122.312312422547
A10_L | 1 | Reaper_PLY_R5G_BATCH_02_OF_04_6mm_PROVISIONAL.dxf | -273.9368353712779 | -27.896682069332826
A62_F | 1 | Reaper_PLY_R5G_BATCH_03_OF_04_6mm_PROVISIONAL.dxf | -10.0 | -110.64445
A05_L | 1 | Reaper_PLY_R5G_BATCH_03_OF_04_6mm_PROVISIONAL.dxf | -10.0 | -281.4296065723969
A07_L_O | 1 | Reaper_PLY_R5G_BATCH_03_OF_04_6mm_PROVISIONAL.dxf | -10.0 | -231.46269616783795
A54 | 1 | Reaper_PLY_R5G_BATCH_03_OF_04_6mm_PROVISIONAL.dxf | -532.244427655014 | 46.71392342760319
A35_R | 1 | Reaper_PLY_R5G_BATCH_03_OF_04_6mm_PROVISIONAL.dxf | -198.66319 | -325.14619620863823
A24_L | 1 | Reaper_PLY_R5G_BATCH_03_OF_04_6mm_PROVISIONAL.dxf | -133.3367940892701 | -288.75637620863824
A62_DR | 1 | Reaper_PLY_R5G_BATCH_03_OF_04_6mm_PROVISIONAL.dxf | -269.3368340892701 | -217.68664905980117
A07_R_D1 | 1 | Reaper_PLY_R5G_BATCH_03_OF_04_6mm_PROVISIONAL.dxf | -456.58126302627414 | 101.03012094019883
A53_L | 1 | Reaper_PLY_R5G_BATCH_03_OF_04_6mm_PROVISIONAL.dxf | -669.6 | -285.2150827231061
A62_A | 1 | Reaper_PLY_R5G_BATCH_04_OF_04_6mm_PROVISIONAL.dxf | -10.0 | -157.35837000000004
A05_R | 1 | Reaper_PLY_R5G_BATCH_04_OF_04_6mm_PROVISIONAL.dxf | -10.0 | -308.96975656836605
A07_R_O | 1 | Reaper_PLY_R5G_BATCH_04_OF_04_6mm_PROVISIONAL.dxf | -10.0 | -251.67607616380718
A34 | 1 | Reaper_PLY_R5G_BATCH_04_OF_04_6mm_PROVISIONAL.dxf | -181.94999999072002 | -236.47037
A04 | 1 | Reaper_PLY_R5G_BATCH_04_OF_04_6mm_PROVISIONAL.dxf | -481.99243 | -122.60486620460722
A44_R | 1 | Reaper_PLY_R5G_BATCH_04_OF_04_6mm_PROVISIONAL.dxf | -980.2416308052199 | 76.46745379539277
A25 | 1 | Reaper_PLY_R5G_BATCH_04_OF_04_6mm_PROVISIONAL.dxf | -450.55881041857924 | -252.88294620460726
A26 | 1 | Reaper_PLY_R5G_BATCH_04_OF_04_6mm_PROVISIONAL.dxf | -450.5588114815653 | -94.82288620460722
A53_R | 1 | Reaper_PLY_R5G_BATCH_04_OF_04_6mm_PROVISIONAL.dxf | -388.23431233396855 | -312.88294620460726
A01_R | 1 | Reaper_PLY_R5G_BATCH_04_OF_04_6mm_PROVISIONAL.dxf | -349.69698941420677 | -370.36227656836604

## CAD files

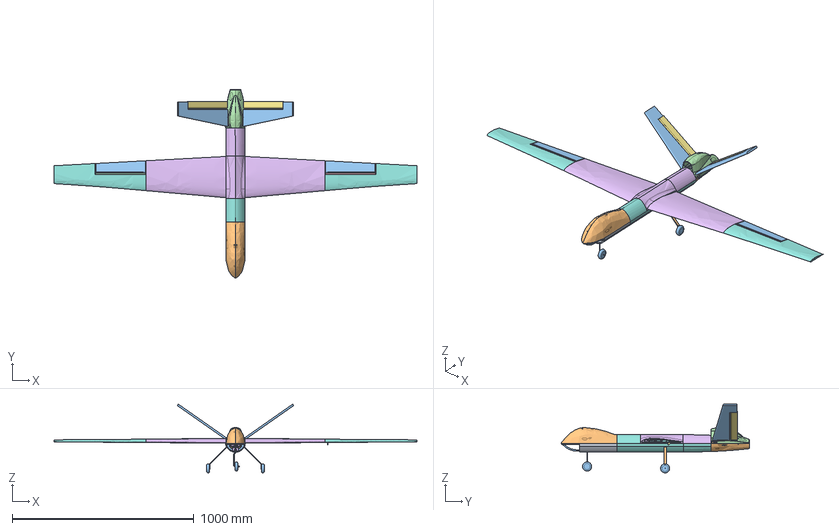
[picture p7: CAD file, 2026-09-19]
Manufacturing/05_Assembly/MQ9_Revised_Assembly.step
2000.0 x 1040.3 x 379.1 mm
A01
A02
A03
A04
A05
A06
A07
A08
A09
A10
A11
A12
A13
A14
A15
A16
A17
A18
A20
A21
A22
A23
A24
A25
A26
A27
A31
A32
A34
A35
A36
A37
A38
A39
A41
A42
A43
A44
A45
A46
A47
A48
A49
A51
A52
A53
A54
A55
A56
A57
A58
A59
A60
A62
A01_opposite_wing_manufacturing
A05_opposite_wing_manufacturing
A07_opposite_wing_manufacturing
A10_opposite_wing_manufacturing
A24_opposite_wing_manufacturing
A35_opposite_wing_manufacturing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

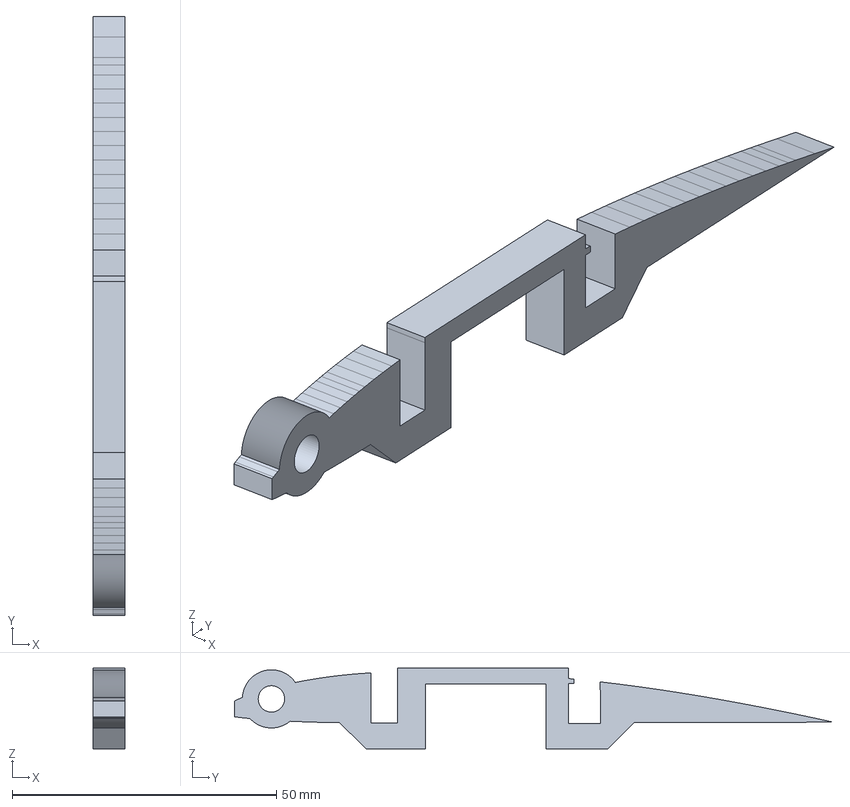
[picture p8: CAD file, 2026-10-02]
CAD/Parts/A44_R.step
6.00 x 113.4 x 15.3 mm

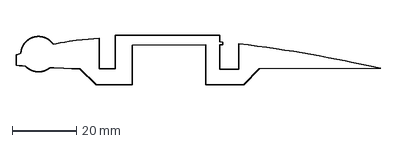
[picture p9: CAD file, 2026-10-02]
CAD/Secondary_Removal/A44_L_finished_paring_template_1to1.dxf
113.4 x 15.3 mm

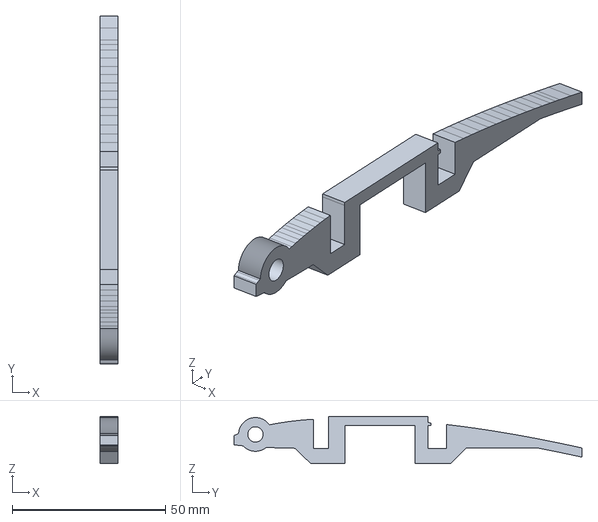
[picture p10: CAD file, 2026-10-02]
CAD/Stock_Blanks/A44_L.step
6.00 x 113.4 x 15.3 mm

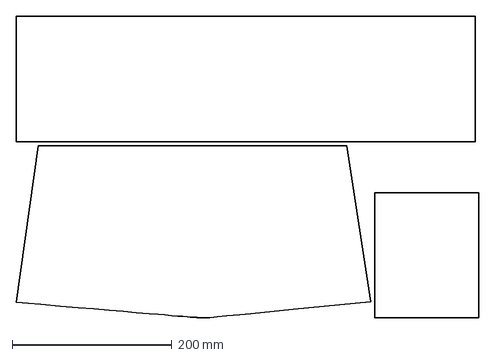
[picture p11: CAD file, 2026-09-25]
Foam/REAPER_R5E_FOAM_400x600_PANEL_02.dxf
578.1 x 377.4 mm

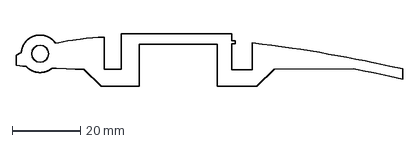
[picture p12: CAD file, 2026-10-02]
Plywood/Individual/A44_R.dxf
113.4 x 15.3 mm

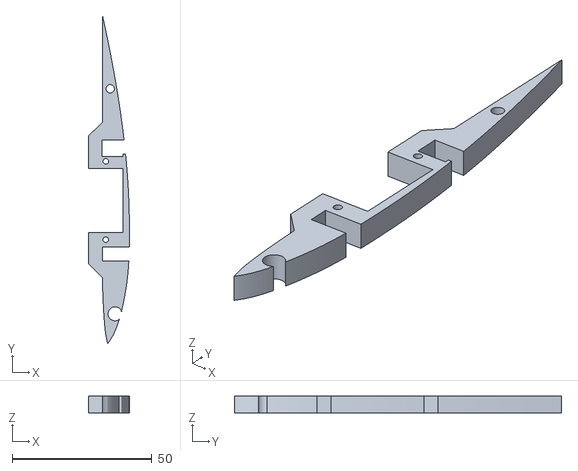
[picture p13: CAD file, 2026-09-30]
Print/Individual/A44_L_PLAplus_4W_100RECT_NOSUP_L0p2_B5.stl
14.6 x 117.0 x 6.00

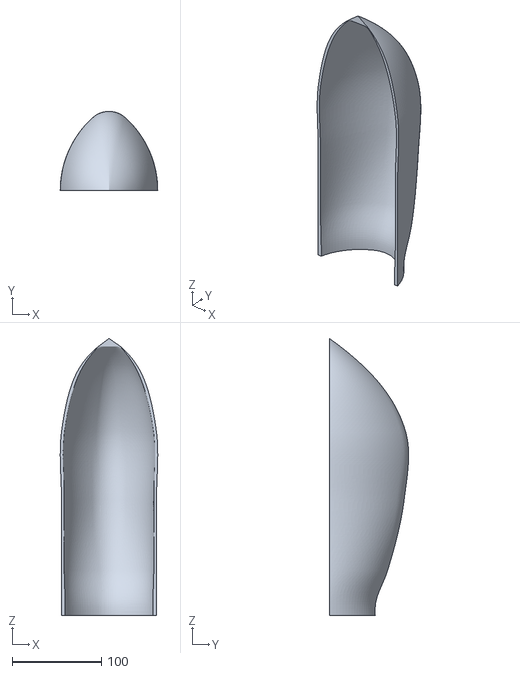
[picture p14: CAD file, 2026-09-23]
Print/N1_Reference_Already_Printed.stl
109.0 x 88.6 x 309.7

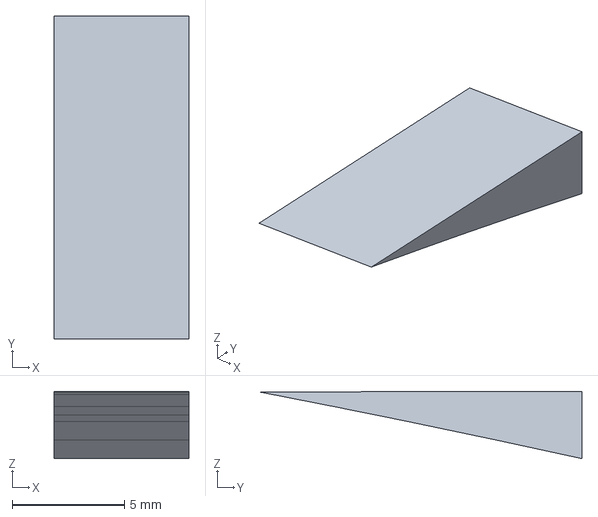
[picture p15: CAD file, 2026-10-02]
CAD/Secondary_Removal/A44_L_tail_underside.step
6.00 x 14.4 x 3.00 mm

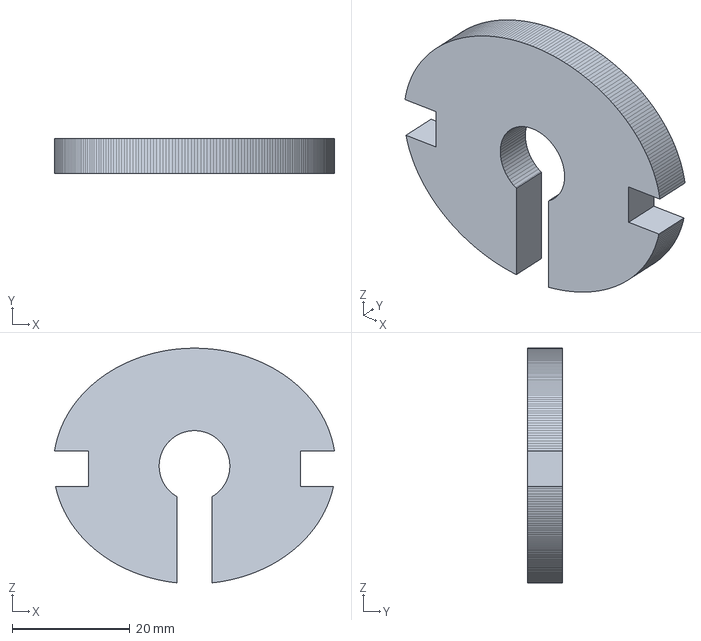
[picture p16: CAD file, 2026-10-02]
CAD/Stock_Blanks/A26.step
47.5 x 6.00 x 39.8 mm

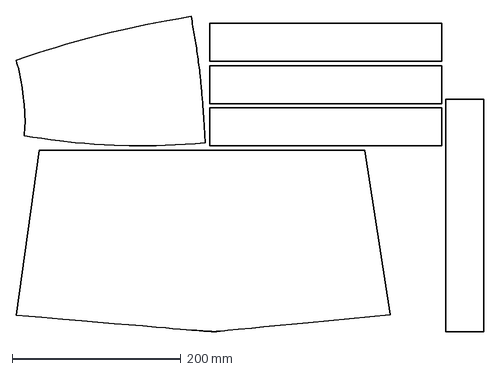
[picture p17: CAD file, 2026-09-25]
Foam/REAPER_R5E_FOAM_400x600_PANEL_03.dxf
554.1 x 373.3 mm

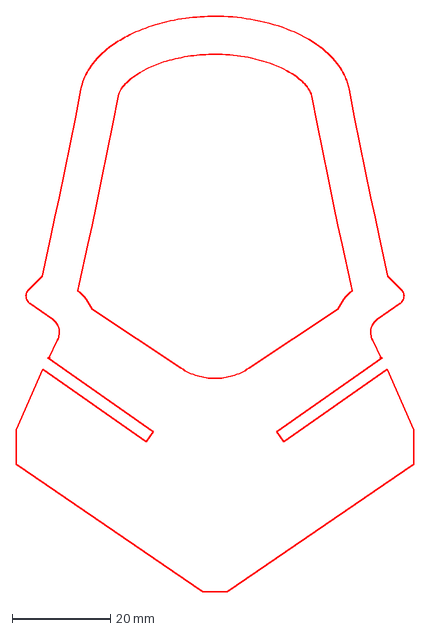
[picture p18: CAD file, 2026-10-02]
Plywood/Individual/A18.dxf
81.0 x 117.3 mm

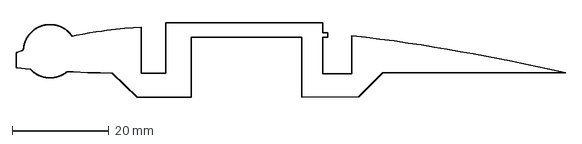
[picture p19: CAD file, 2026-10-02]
Plywood/Paring_Templates/A44_R_finished_paring_template_1to1.dxf
113.4 x 15.3 mm

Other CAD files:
Plywood/Batches/Reaper_PLY_R5G_BATCH_03_OF_04_6mm_PROVISIONAL.dxf
Plywood/Reaper_ALL_PLYWOOD_R5G_6mm_PROVISIONAL.dxf
CAD/Parts/A44_L.step
Plywood/Batches/Reaper_PLY_R5G_BATCH_04_OF_04_6mm_PROVISIONAL.dxf
CAD/Archive_Fit_Prototypes/A26.step
CAD/Archive_Fit_Prototypes/A44_L.step
CAD/Archive_Fit_Prototypes/A44_R.step
CAD/Archive_Secondary_R5F/A62_A_AFT_TRIM.step
CAD/Archive_Secondary_R5F/A62_F_1.step
CAD/Parts/A01_L.step
CAD/Parts/A01_R.step
CAD/Parts/A04.step
CAD/Parts/A05_L.step
CAD/Parts/A05_R.step
CAD/Parts/A06.step
CAD/Parts/A07_L_D1.step
CAD/Parts/A07_L_D2.step
CAD/Parts/A07_L_I.step
CAD/Parts/A07_L_O.step
CAD/Parts/A07_R_D1.step
CAD/Parts/A07_R_D2.step
CAD/Parts/A07_R_I.step
CAD/Parts/A07_R_O.step
CAD/Parts/A08.step
CAD/Parts/A10_L.step
CAD/Parts/A10_R.step
CAD/Parts/A11.step
CAD/Parts/A12.step
CAD/Parts/A13.step
CAD/Parts/A15.step
CAD/Parts/A16.step
CAD/Parts/A17.step
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

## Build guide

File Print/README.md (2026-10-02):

# Print files

Most parts are already printed. The three missed unchanged source files below are supplied one each; reuse other completed prints after inspection.

| Quantity | Part and file | Source reference settings |
|---|---|---|
| 1 | [A23 left fixed aileron hinge rail](Individual/A23_3W_15GYR_NOSUP_L0p2_B8.stl) | 3 walls, 15% gyroid, 0.2 mm layers, 0.4 mm nozzle, supports off, 8 mm brim |
| 1 | [A36 right fixed aileron hinge rail](Individual/A36_3W_15GYR_NOSUP_L0p2_B8.stl) | Same as A23 |
| 1 | [HTRB right tail horn backing plate](Individual/HTRB_3W_100RECT_NOSUP_L0p2_B5.stl) | 3 walls, 100% rectilinear, 0.2 mm layers, 0.4 mm nozzle, supports off, 5 mm brim |

The source recipes specify PLA+. The shop has PLA available; use its actual spool's recommended temperature/cooling and review the slicer preview. Do not invent an ASA requirement or equate ordinary PLA to a qualified PLA+ structural material. A23/A36 are supplied with the span upright, approximately 270.2 mm tall: confirm actual printable height and bed/brim clearance at unchanged scale. HTRB lies flat on its broad 22 × 24 mm face, 1.5 mm thick. HTRB is the backing plate, not the tail horn itself. Watertight meshes and unchanged hashes do not establish real fit or load strength.

A11/A21 moving aileron STLs also remain unchanged; retain existing good prints. [Print_Names_and_Settings.csv](../Data/Print_Names_and_Settings.csv) contains the existing reference recipes for every current print. W means wall loops; GYR/RECT mean gyroid/rectilinear; SUP/NOSUP indicate reference supports; L0p2 is 0.2 mm layer height; B is brim width. An STL does not embed these settings.

A26 and A44_L/R are plywood in the current requested R5G cutting set. Their earlier printed-fit geometry and reference settings are preserved in Archive_Fit_Prototypes and are superseded manufacturing options. Do not print them for the current cutting job or treat a previous PLA A26 fit prototype as a qualified motor mount.

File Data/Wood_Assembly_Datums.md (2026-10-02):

# Reaper R5G wood assembly

The current full requested recut set contains 37 nominal 6 mm plywood pieces, including A26 and reinforced A44_L/R. Use the single combined R5G DXF, part map and complete beginner guide. Physical stock thickness/kerf, receiver batch, actual motor mounting and assembly fit remain unverified.

The DXF describes laser stock, while CAD/Parts contains the finished assembly geometry. Shallow rebates and sacrificial allowances require the exact illustrated secondary operation. Do not through-cut their bounding boxes or thin an entire part. Grain is carried through each flattening/nesting transform: all current panel grain vectors are parallel to stock X; A18 is intentionally rotated 90 degrees.

Current fit corrections:

- A18: the user confirmed 0.5 mm total clearance, implemented as a 0.25 mm normal inset of opposed upper A12 receiver-facing perimeter edges. Its inner opening, bottom keel interface and 6 mm thickness are unchanged. Delivered adapted A12 has a 6.30 mm axial slot; the raw original source has a 2.5 mm slot and cannot accept 6 mm stock. Verify the actual print batch and insertion order before bonding. Installed CAD noninterference does not prove insertion; straight translation probes are blocked, so the actual tilt/order fit remains a required check.
- A01_L/R: extremely thin source toe/shelf extensions are removed along the retained spar contact planes; the 5 mm rear-rod hole, its axis and broad spar contacts remain. Fixture the original rear-spar height and foil alignment during bonding because the removed shelf previously acted as a register.
- A62_A: laser length is 482.650 mm, with the prior 13.015 mm aft trim incorporated. A18's nominal 6 mm notch, Z-31 floor and 30 mm² nominal seat remain. A62_F source length is 529.070452 mm and its local A54 seat still needs the source side relief.
- A44_L/R: retain the reinforced front-rod seat and servo-bay roof. The entire original trailing taper and A53 bond footprint are restored. A 3 mm minimum vertical web protects that thin tail during laser cutting. Pare only the sacrificial underside allowance to the supplied finished profile before bonding A53 or closing the skin; do not shorten the trailing tip. Manual actual servo/retainer hole placement and local foam relief remain required. Exact removal STEP and non-laser paring templates are supplied.
- A26: plywood plate with zero motor screw holes; [motor fit notes](A26_Motor_Mount.md) govern actual rear-frame dry-fit, real-motor marking, hardware engagement and loaded qualification.

## Assembly order and retained datums

1. Join A62_F and A62_A at world Y100 mm on a straight flat jig. A62_DL and A62_DR bond on opposite faces from Y40 to Y160 mm. Align their lower edges with the keel at Z-41.7139 mm. Each lap bonds to the full 7.5 mm-high keel band for 60 mm on each half, about 450 square mm per half per face. The butt ends locate the halves; the side laps transfer load. Cure to the actual adhesive instructions before loading.
2. Dry-fit A13/A43 horizontal frames, body formers and keel with frame upper face Z0. Complete local relief before bonding; do not thin the whole frame or former. Install the original gear crossmembers/crossplate, but defer actual landing-gear hardware until after midsems. Their presence does not prove purchased-gear attachment, steering clearance or load spreading.
3. A18 occupies Y454.5 to Y460.5 mm. Prove the actual adapted A12 receiver insertion/order and service access before glue. A26 occupies Y576.65 to Y582.65 mm, motor axis X0/Z-2.5 mm. R5G A26 has zero motor screw holes. Dry-fit the actual rear frame/keel/receiver first, then hand-mark the real motor. A62_A ends flush at Y582.65; do not repeat the previous 13.015 mm trim. Check driver, heads, washers, wiring, seating and safe thread depth using actual hardware rather than nominal CAD cylinders.
4. Join rear wing spar halves at X+360 mm on the right, mirrored on the left. Two 100 mm face laps span X310 to X410 mm, giving 50 mm overlap per half and about 300 square mm contact per face per half. Keep the spar straight in a jig through full adhesive cure.
5. Assemble each wing's front spar, joined rear spar, A01 rear-rod support and inner/middle/outer ribs. Fixture A01's original rear-spar height because its fragile shelf is removed. Both whole 5 x 1000 mm rods cross the fuselage: front axis Y60.4543/Z15.6325 mm and rear Y100.5004/Z15.0705 mm, each spanning X-500 to X500. Do not cut or butt-join them. Current A44 has a closed front-rod seat with a 3 mm ligament; plan axial rod insertion before bonding/skin closure.
6. Pare only A44's sacrificial underside tail allowance to the supplied full finished taper before bonding A53. Preserve the whole tip and reinforced servo-bay roof, mark actual servo/retainer holes after fitting, and qualify the local foam relief. No claim of loaded capacity follows from the geometric contact area.
7. Fit wooden aileron endplates to the unchanged revised printed controls and fixed rails. A53's inboard datum remains about X493 mm, with its 6 mm thickness extending outboard; the control was previously shortened to suit. Outer plates extend away from the moving controls. The 2 mm holes are pilots: align/ream to the real short bicycle-spoke pivots on the common hinge line and provide positive pivot retention. A friction fit alone is insufficient.
8. Dry-fit the source foam around the finished frame, preserving outer paper and making only documented internal relief. Inspect joints, installed controls, wire routing and service access before closure. Weigh the completed structure before physical balance/performance acceptance.

## Fixed body stations

| Member | World assembly datum, mm |
|---|---|
| A13 front horizontal frame | Upper face Z0; original front end near Y-435.01 |
| A34 front former | Forward face Y-130 |
| A54 body former | Forward face Y-5 |
| A25 gear crossmember | Forward face Y125 |
| A48 gear crossmember | Forward face Y142.7 |
| A16 body former | Forward face Y233.65 |
| A04 rear body former | Forward face Y384.65 |
| A18 tail carrier bulkhead | Aft face Y460.5 |
| A26 plywood motor firewall | Aft face Y582.65 |

## Local fitting: stock versus finished shape

Secondary_Dimensions.json and CAD/Secondary_Removal show actual removal regions. A depth interval spanning 0 to 6 mm does not mean remove an entire rectangular bounding box: the region can combine a through-notch edge with an adjacent shallow rebate. Removal solids are finishing tools, not extra aircraft pieces.

- A43: local seats at Y125 to131, Y142.7 to148.7, Y233.65 to239.65 and Y384.65 to390.65 mm. At the first two remove 1 mm locally from the underside, retaining 5 mm. Body-former seats retain about 5 mm at representative patches; one original curved rear patch samples 4.83 mm. Stop at the illustrated mating shape, preserving surrounding full thickness. Do not force a curved source patch into an invented uniform 5 mm plane.
- A05_R/L: root and middle-rib notch/tab relief at X53 to59 and X247.35 to253.35 mm, mirrored on the left. The removal combines edge and face fitting. Do not apply one blanket sanding depth; use the mating rib and finished geometry as the stop.
- A07_R_I/L_I: corresponding root/middle-rib stations; representative tabs retain 5 mm locally while the rest stays 6 mm.
- A62_F: A54 seat at Y-5 toY1 mm. Local side relief retains 5 mm (nominally 0.5 mm per side); retain the surrounding keel band and match the actual former. A62_A's aft cut is already incorporated into its current stock profile.
- A53_R/L and A07_R_O/L_O: source edge wedges around 0.03 mm and 0.015 mm respectively. Dress only if the actual dry-fit needs it; preserve the source outline and pivot-support material.
- A44_L/R: use the exact underside-tail removal and the non-laser 1:1 paring templates. The source A53 bond footprint is restored at about 30.614 square mm per side. Actual bond quality and structural proof loading remain required.

These are geometric attachment datums, not plywood/adhesive/fatigue allowables. Actual joints, wing/frame, hardware, propulsion, balance and operation require the guide's physical gates.

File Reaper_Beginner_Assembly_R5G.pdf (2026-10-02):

START

# Reaper: build one stage at a time

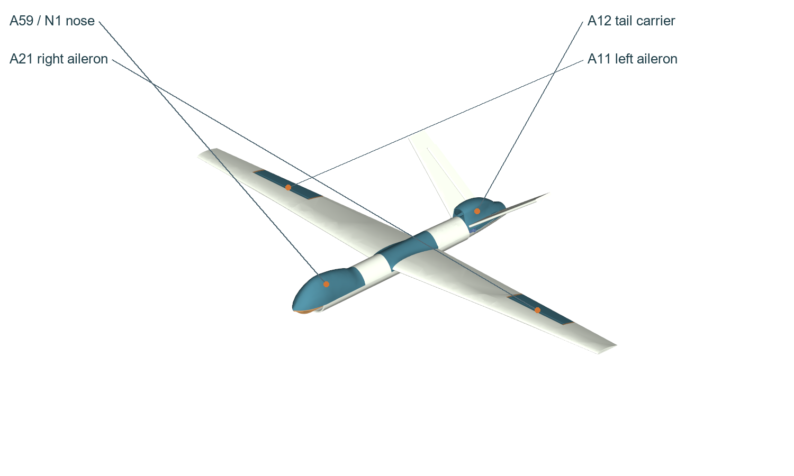
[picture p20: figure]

Intended upright V-tail aircraft from actual assembly CAD. Landing gear and propeller are absent at this build stage.
DARTS founding project - registration pending. This complete follow-along guide takes the current cut parts and prints through assembly, wiring and bench checks. Landing gear is a later stage after midsems.

Use the complete current plywood cutting set, reinforced A44_L/R outer ribs and no-motor-hole A26 firewall blank. Reuse sound foamboard and prints. A11/A21 ailerons, A23/A36 fixed rails and HTRB right tail-horn backer are supplied unchanged for the missed prints.

Read the next step before bonding; for an already-built stage perform its check. Keep the propeller off throughout assembly, wiring and configuration. Physical fit, cured joints, control operation and propulsion must be proved on the aircraft before pilot acceptance.

Abhinav Pullela . mcarkade | Contents | 1

START

# Contents

Reaper: build one stage at a time | 1
Start with the parts you have | 4
Tools, glue and curing | 5
Fuselage wood | 6
Fuselage wood continued | 7
Fuselage wood continued | 8
Wing wood | 9
Wing wood continued | 10
Wing wood continued | 11
Wing wood continued | 12
Printed aircraft parts | 13
Printed aircraft parts continued | 14
Printed aircraft parts continued | 15
Foam installed shapes | 16
Foam installed shapes continued | 17
Foam installed shapes continued | 18
Cut the complete plywood set on two stock panels | 19
01. Finish only the marked wood seating patches | 20
A43 underside seats and curved rear relief | 21
02. Align the two keel halves | 22
Keel lengths and local notch finishing | 23
03. Bond both keel side laps | 24
04. Dry-fit the horizontal body frames | 25
05. Add the two forward body formers | 26
06. Add the two aft body formers | 27
07. Fit the gear-bay pieces and tail bulkhead | 28
Identify the tail-carrier receiver before glue | 29
08. Trial the printed body parts, then bond the wood | 30
09. Align each rear wing spar | 31
10. Bond both face laps on each spar | 32
11. Build the right wing with its reinforced plywood rib | 33
A01 rod support and spar-height jig | 34
12. Build the left wing and compare both sides | 35
Pare the A44 tail underside before assembly | 36
A44 paring templates at actual size | 37
Reinforced A44 seats and skin clearance | 38
13. Fit both roots and the two whole carbon rods | 39
14. Install the fixed aileron rails and endplates | 40
15. Fit the unchanged ailerons and captive pins | 41
16. Mount wing servos, horns and pushrods | 42
17. Form and fit the fixed upright V-tail | 43
18. Laminate the moving tail controls and hinge them | 44
19. Fit the two tail servos and backed horns | 45
20. Check the complete open structure | 46

START

# Contents continued

21. Form the inner wing skins you already cut | 47
22. Dry-fit outer skins and keep access open | 48
23. Place and restrain the battery and electronics | 49
24. Place GPS, pitot and airspeed tubes | 50
25. Dry-fit the plywood motor firewall blank | 51
Motor fitting detail and manual drilling | 52
26. Connect high-current power with the prop off | 53
Power and motor connection map | 54
27. Connect servo power and receiver | 55
28. Connect sensors and the SiK air radio | 56
Receiver, sensor and radio map | 57
Complete wiring foldout | 58
29. Power carefully and prove the open installation | 59
30. Install firmware and save the starting settings | 60
Assign the actual outputs explicitly | 61
31. Calibrate radio, attitude, compass and airspeed | 62
Pair the SiK radios and prove telemetry | 63
32. Check motor direction without a propeller | 64
33. Prove every control direction and failsafe | 65
34. Fit lower body wraps after open checks | 66
35. Fit removable top covers and centre fairing | 67
36. Park safely until gear work after midsems | 68
Physical acceptance gate 1: structure and balance | 69
Physical acceptance gate 2: propulsion and ground | 70
If a check fails | 71
Foam ID to installed shape | 72
Print the missed aircraft pieces | 73
Record acceptance and keep the sources | 74

START

# Start with the parts you have

Right and left mean the pilot looking toward the nose. The nose is the narrow front end; the motor is at the rear. In drawings, X runs across the wings, Y increases aft and Z is upward. All quoted dimensions are millimetres unless stated otherwise.

The source wing span is 2.00 m. Two whole 5 x 1000 mm carbon rods support the wings across the centre. Plywood is nominal 6 mm and foamboard nominal 5 mm; measure your stock. Never scale parts to solve a fit.

Sort pieces into fuselage, right wing, left wing, tail and electronics bags. Match IDs to the part pictures in this guide. A40 is already incorporated into the unified A62 keel; do not stack another A40. Match A44_L/R to the reinforced plywood profiles shown here; their closed front-rod seats change insertion order and require local skin relief.

FW01/FW02 inner foam skins may be whole R5C cuts or R5E ROOT/TIP pairs. Both use the same final outline. Keep whole skins intact; join only skins already supplied as two pieces. The complete plywood recut contains all current quantities. Laser cutting makes through-profiles; the local shallow seating relief in the next pages remains a hand-finishing operation. Measure stock and a kerf/fit coupon first.

START

# Tools, glue and curing

Use a flat board, straightedge, square, calipers, sharp knife, sanding block, clamps, hand drill, smooth trial pin, reinforced tape, zip ties, Velcro straps, soldering iron, heat-shrink and multimeter. For early servo centring use a regulated 5 V supply and standalone servo tester with neutral mode; availability is unconfirmed. A current-limited source helps the first electrical check.

For close wood-to-wood joints, use a wood adhesive approved for the plywood and clamp full contact. For print-to-wood joints, lightly abrade only the bond patch, remove dust, and qualify an adhesive explicitly compatible with both the chosen filament and wood. A gap-filling two-part epoxy is a candidate only after its offcut test passes.

For foam use an adhesive explicitly approved for its foam core and paper. Ordinary CA and solvent glue can damage exposed foam; test the exact product first. Hot glue can locate light equipment but must not be the sole battery restraint or proof of a loaded joint.

Write the exact adhesive name, mix ratio if required, working time, clamp time and full-cure time from its label on a bench card. Apply at the stated temperature. Keep each joint supported for the label clamp time and unloaded until full cure. No exact adhesive is identified in the local BOM, so there is no universal hour value to copy.

Bond one wood lap, one print-to-wood offcut and one foam fold first. After full cure pull and bend the samples. Stop if paper peels, plastic separates, the core melts or the bond remains soft; choose and test a compatible adhesive before using it on the aircraft.

Check before continuing: Continue only when the exact adhesives, clamp times and full-cure times are written down and the sample joints pass.

# Fuselage wood

PART PICTURES

Match ID, shape and side. Quantities refer to installed pieces; foam cutting patterns can combine several shapes. See the foam ID table for blank counts.

A04 - Rear body former

Plywood, nominal 6 mm; quantity 1

A13 - Front horizontal fuselage frame

Plywood, nominal 6 mm; quantity 1

A16 - Body former at Y233.65mm

Plywood, nominal 6 mm; quantity 1

A18 - Tail-carrier bulkhead - upper perimeter clearance

Plywood, nominal 6 mm; quantity 1

A25 - Forward main-gear crossmember

Plywood, nominal 6 mm; quantity 1

A26 - Motor firewall blank - hand drill motor pattern

Plywood, nominal 6 mm; quantity 1

# Fuselage wood continued

PART PICTURES

Match ID, shape and side. Quantities refer to installed pieces; foam cutting patterns can combine several shapes. See the foam ID table for blank counts.

A34 - Front body former at Y-130mm

Plywood, nominal 6 mm; quantity 1

A43 - Aft horizontal fuselage frame

Plywood, nominal 6 mm; quantity 1

A47 - Main-gear crossplate

Plywood, nominal 6 mm; quantity 1

A48 - Aft main-gear crossmember

Plywood, nominal 6 mm; quantity 1

A54 - Body former at Y-5mm

Plywood, nominal 6 mm; quantity 1

A62_F - Lower fuselage keel - front half

Plywood, nominal 6 mm; quantity 1; length 529.07 mm

PART PICTURES

# Fuselage wood continued

Match ID, shape and side. Quantities refer to installed pieces; foam cutting patterns can combine several shapes. See the foam ID table for blank counts.

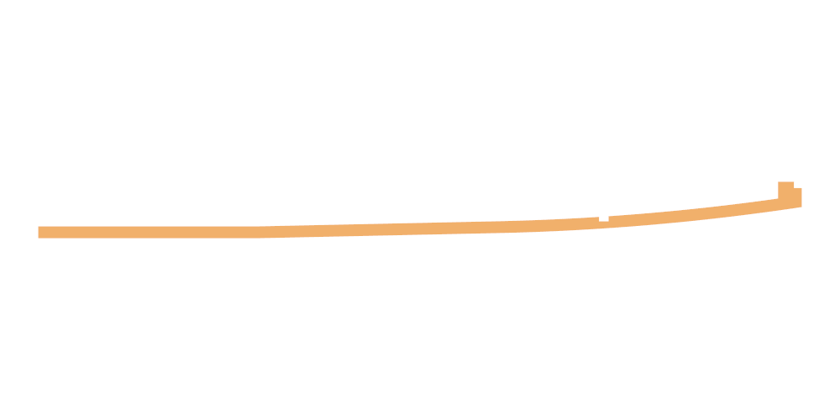
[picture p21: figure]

A62_A - Lower fuselage keel - aft half

Plywood, nominal 6 mm; quantity 1; length 482.65 mm

A62_DL - Keel joint - left side lap

Plywood, nominal 6 mm; quantity 1; length 120.0 mm

A62_DR - Keel joint - right side lap

Plywood, nominal 6 mm; quantity 1; length 120.0 mm

# Wing wood

PART PICTURES

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

A01_R - Rear-rod support rib - right

Plywood, nominal 6 mm; quantity 1

A01_L - Rear-rod support rib - left

Plywood, nominal 6 mm; quantity 1

A05_R - Front wing spar - right

Plywood, nominal 6 mm; quantity 1

A05_L - Front wing spar - left

Plywood, nominal 6 mm; quantity 1

A10_R - Outer aileron endplate - right

Plywood, nominal 6 mm; quantity 1

A10_L - Outer aileron endplate - left

Plywood, nominal 6 mm; quantity 1

# Wing wood continued

PART PICTURES

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

A24_R - Middle wing rib at span250mm - right

Plywood, nominal 6 mm; quantity 1

A24_L - Middle wing rib at span250mm - left

Plywood, nominal 6 mm; quantity 1

A35_R - Inner wing rib at span53mm - right

Plywood, nominal 6 mm; quantity 1

A35_L - Inner wing rib at span53mm - left

Plywood, nominal 6 mm; quantity 1

A44_R - Reinforced outer wing rib - right

Plywood, nominal 6 mm; quantity 1

A44_L - Reinforced outer wing rib - left

Plywood, nominal 6 mm; quantity 1

# Wing wood continued

PART PICTURES

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

A53_R - Inner aileron endplate - right

Plywood, nominal 6 mm; quantity 1

A53_L - Inner aileron endplate - left

Plywood, nominal 6 mm; quantity 1

A07_R_I - Rear wing spar - right inboard section

Plywood, nominal 6 mm; quantity 1

A07_R_O - Rear wing spar - right outboard section

Plywood, nominal 6 mm; quantity 1

A07_R_D1 - Rear wing spar - right first face lap

Plywood, nominal 6 mm; quantity 1

A07_R_D2 - Rear wing spar - right second face lap

Plywood, nominal 6 mm; quantity 1

PART PICTURES

# Wing wood continued

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

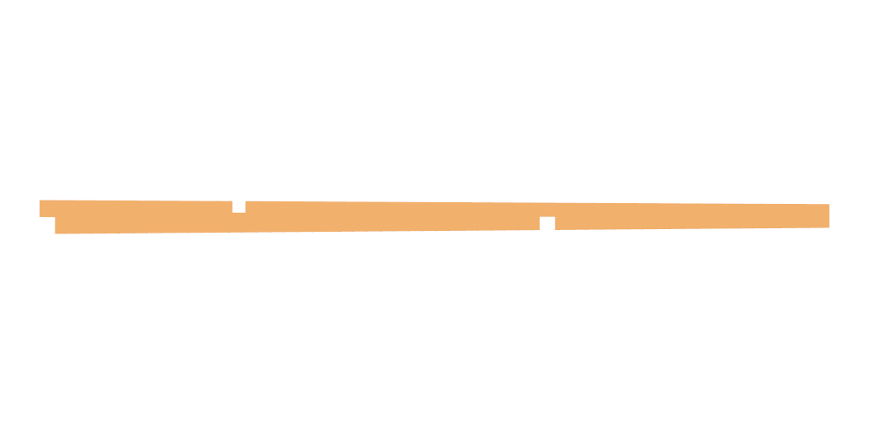
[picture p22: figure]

A07_L_I - Rear wing spar - left inboard section

Plywood, nominal 6 mm; quantity 1

A07_L_O - Rear wing spar - left outboard section

Plywood, nominal 6 mm; quantity 1

A07_L_D1 - Rear wing spar - left first face lap

Plywood, nominal 6 mm; quantity 1

A07_L_D2 - Rear wing spar - left second face lap

Plywood, nominal 6 mm; quantity 1

# Printed aircraft parts

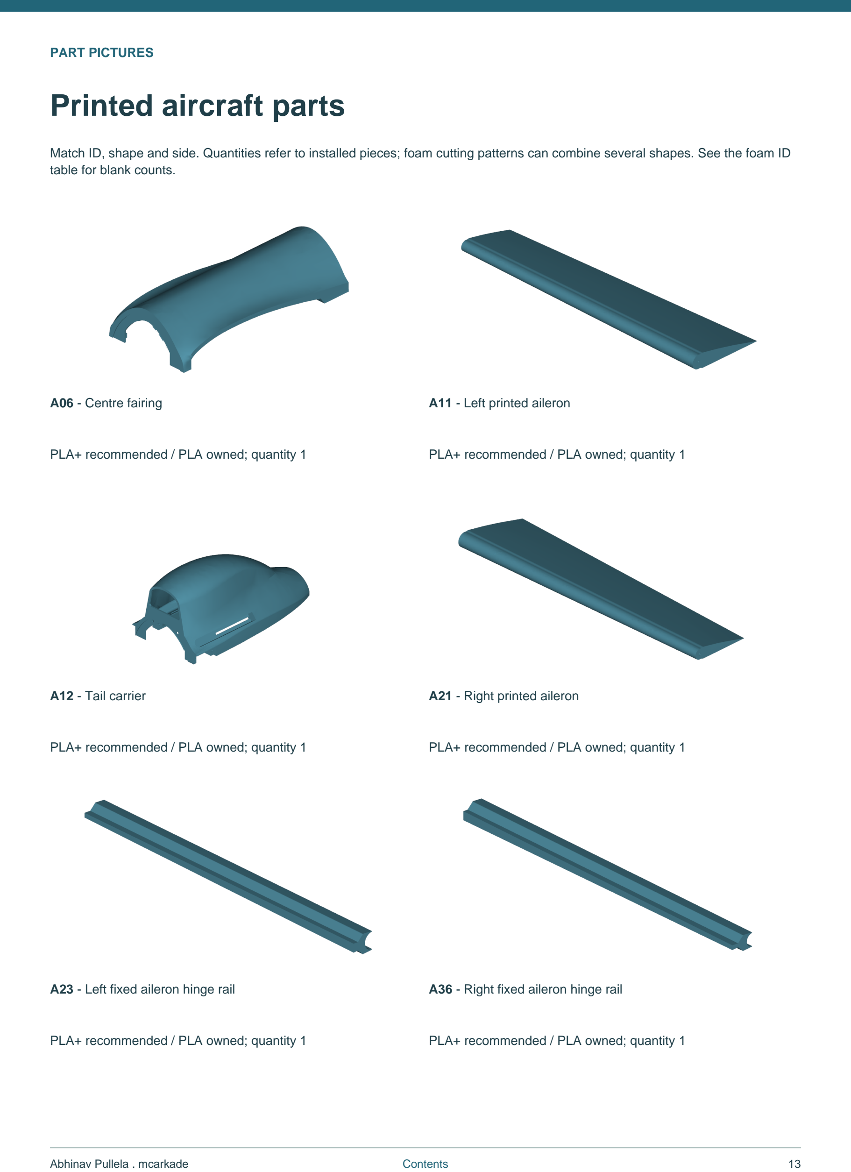
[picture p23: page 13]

PART PICTURES

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

A06 - Centre fairing

PLA+ recommended / PLA owned; quantity 1

A11 - Left printed aileron

PLA+ recommended / PLA owned; quantity 1

A12 - Tail carrier

PLA+ recommended / PLA owned; quantity 1

A21 - Right printed aileron

PLA+ recommended / PLA owned; quantity 1

A23 - Left fixed aileron hinge rail

PLA+ recommended / PLA owned; quantity 1

A36 - Right fixed aileron hinge rail

PLA+ recommended / PLA owned; quantity 1

# Printed aircraft parts continued

PART PICTURES

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

A45 - Right wing root

PLA+ recommended / PLA owned; quantity 1

A55 - Left wing root

PLA+ recommended / PLA owned; quantity 1

A59 - Owned N1 nose, reused

PLA+ recommended / PLA owned; quantity 1

HWR - Right aileron horn

PLA+ recommended / PLA owned; quantity 1

HWL - Left aileron horn

PLA+ recommended / PLA owned; quantity 1

HTR - Right tail horn with base

PLA+ recommended / PLA owned; quantity 1

PART PICTURES

# Printed aircraft parts continued

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

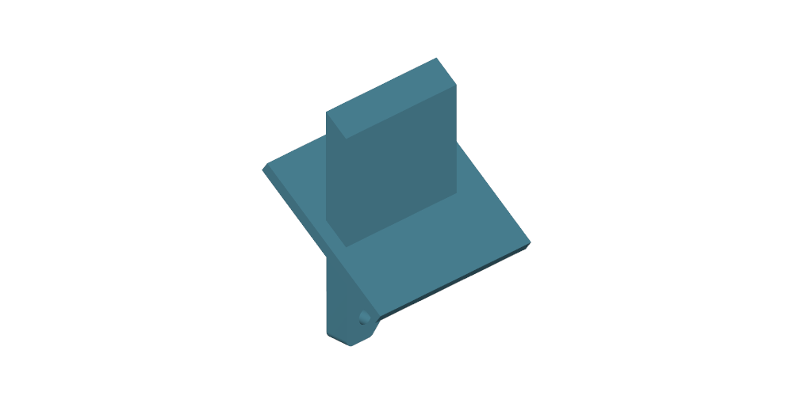
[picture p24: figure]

HTL - Left tail horn with base

PLA+ recommended / PLA owned; quantity 1

HTRB - Right tail horn backing plate

PLA+ recommended / PLA owned; quantity 1

HTLB - Left tail horn backing plate

PLA+ recommended / PLA owned; quantity 1

# Foam installed shapes

PART PICTURES

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

A08 - Forward upper body foam

Foam; quantity 1

A15 - Aft upper body foam

Foam; quantity 1

A17 - Middle lower body foam

Foam; quantity 1

A20 - Tail lower body foam

Foam; quantity 1

A22 - Left fixed V-tail foam

Foam; quantity 1

A27 - Left outer wing foam

Foam; quantity 1

# Foam installed shapes continued

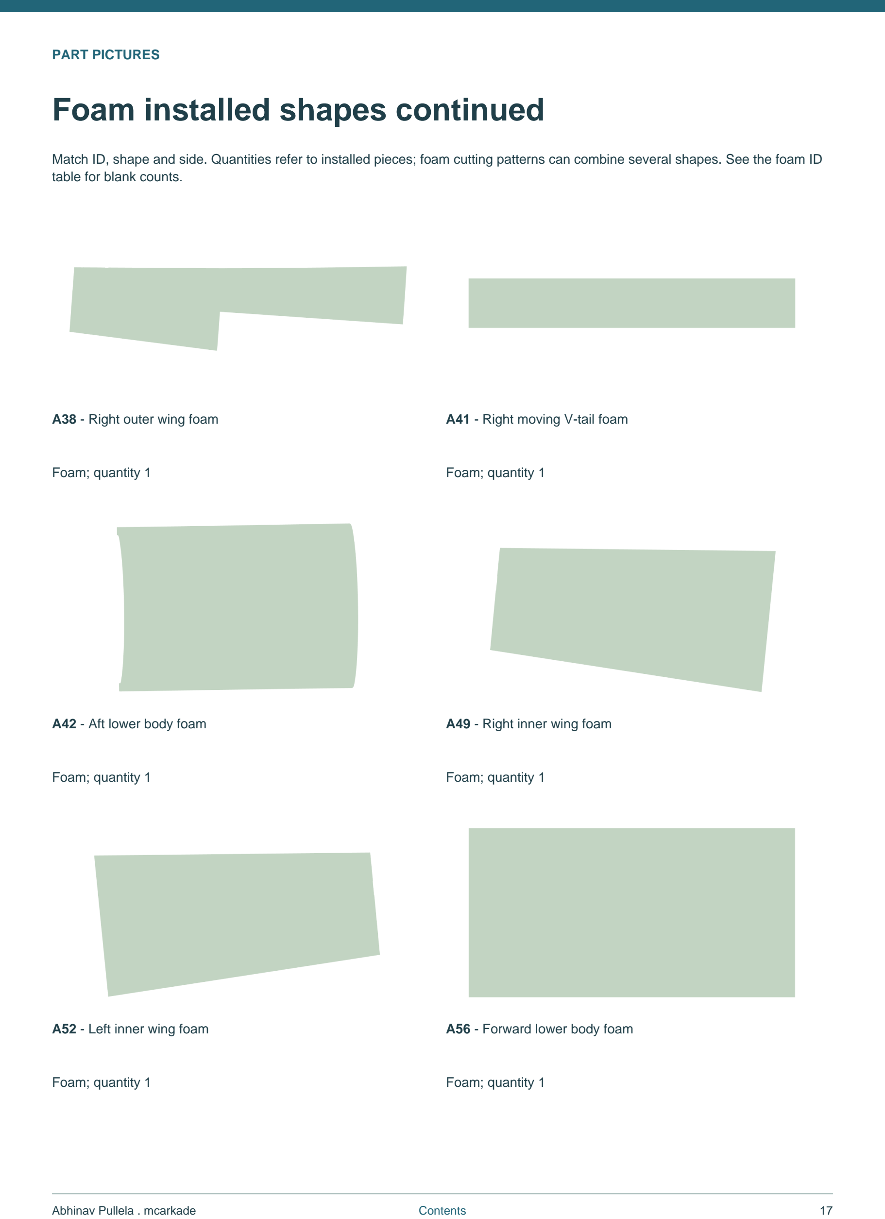
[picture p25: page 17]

PART PICTURES

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

A38 - Right outer wing foam

Foam; quantity 1

A41 - Right moving V-tail foam

Foam; quantity 1

A42 - Aft lower body foam

Foam; quantity 1

A49 - Right inner wing foam

Foam; quantity 1

A52 - Left inner wing foam

Foam; quantity 1

A56 - Forward lower body foam

Foam; quantity 1

PART PICTURES

# Foam installed shapes continued

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

A57 - Right fixed V-tail foam

Foam; quantity 1

A60 - Left moving V-tail foam

Foam; quantity 1

START

# Cut the complete plywood set on two stock panels

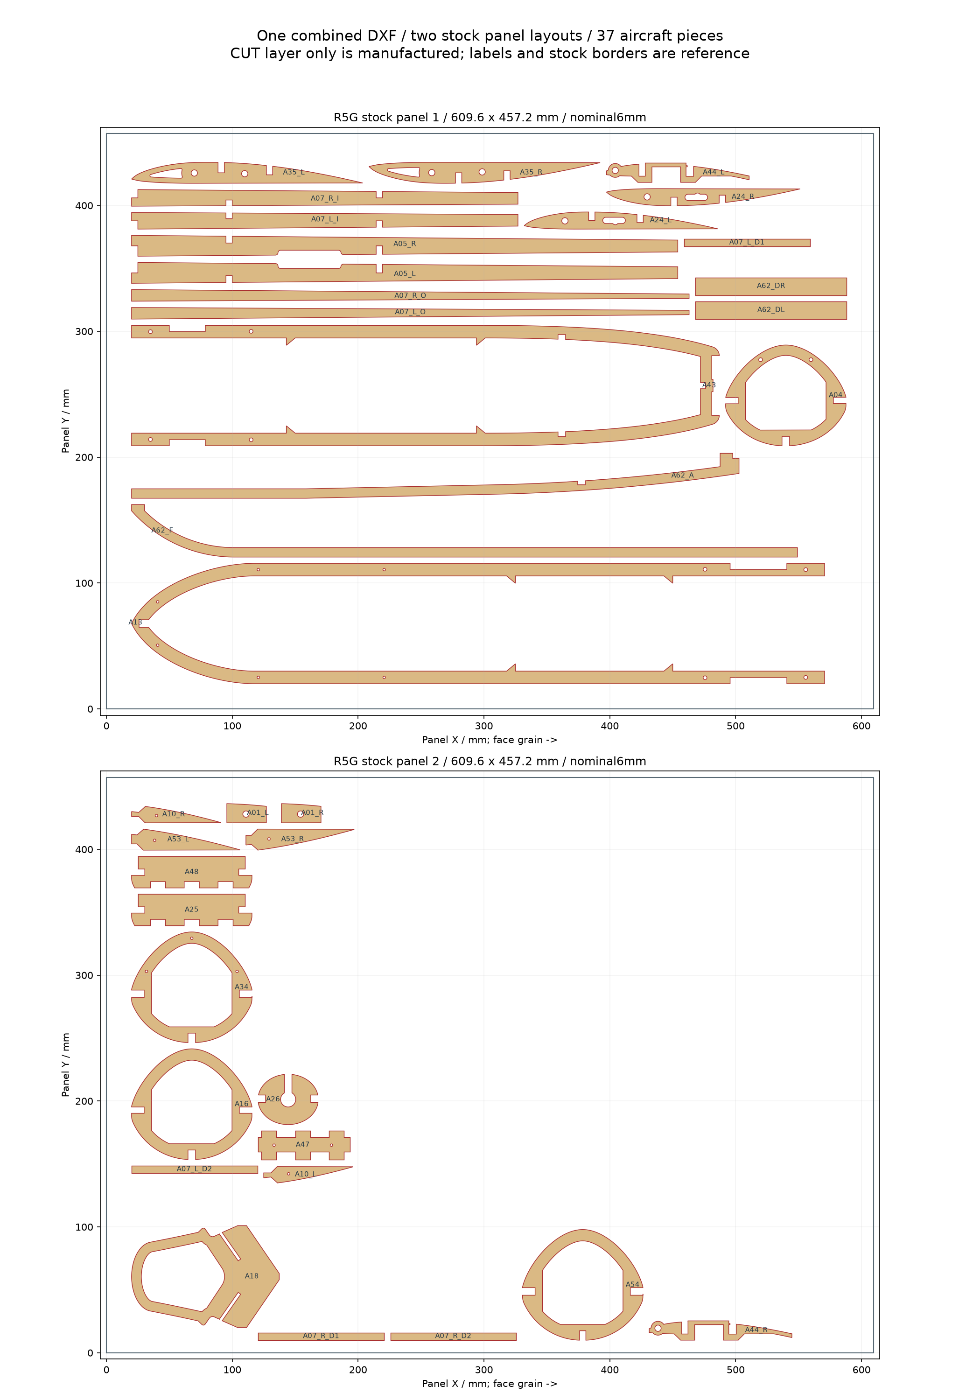
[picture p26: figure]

Both nominal stock layouts in the same file. Reference sheet borders and labels are not laser cuts.
Reaper_ALL_PLYWOOD_R5G_6mm_PROVISIONAL.dxf contains all 37 aircraft wood pieces at quantity 1 each, including mirrored pairs, four rear-spar sections and four face laps, both keel halves/laps, the reinforced A44 pair and no-motor-hole A26. The identification cards show every current part.

One combined DXF contains two separate 609.6 x 457.2 mm stock layouts, nominal 6 mm thick. Stock 1 starts at global X0; stock 2 starts at X659.6. The full drawing width is 1269.2 mm. If the laser bed does not span this width, process each stock region as a separate job on its own sheet without rescaling.

Cut only the CUT layer. Disable REFERENCE_NOT_CUT stock borders and LABELS_NOT_CUT text in the machine job. Preserve the nest rotations and grain direction: the strongest face grain follows each stock panel X axis. Labels and borders are placement references.

Actual stock thickness, grain and kerf are unmeasured. Qualify the critical rod-hole and rib/spar/keel fit coupons before cutting the full set. Kerf compensation is separate from modeled A18 perimeter clearance. After cutting, hand-finish local shallow seats and the sacrificial A44 tail underside to the shown finished taper. Drill hardware holes only against actual parts.

Check before continuing: Two real stock sheets and machine job regions are confirmed; CUT-only selection, scale, grain and fit coupons pass.

STEP 01

# Finish only the marked wood seating patches

Lower: actual removal shapes identify four local A43 seating regions. Orange is material removed, never an extra part or a whole-frame thinning instruction.

Dry-fit complete pieces before glue. Nominal stock is 6 mm; actual thickness and laser kerf remain unmeasured. Through-cut outlines and shallow hand-finished seats are separate operations. Never thin a complete frame to fix a local seat.

On A43 remove only the orange source removal volumes at Y125-131, Y142.7-148.7, Y233.65-239.65 and Y384.65-390.65. The first two flat underside seats lose 1 mm, leaving 5 mm. Rear seats follow their curved removal geometry: a representative residual is about 4.83 mm; the complete bounding box is not a uniform 5 mm rebate.

A05_L/R and A07_L_I/R_I need local rib-tab relief near X53-59 and X247.35-253.35 and their mirrors. A62_F has shallow A54-seat relief at Y-5 to 1, leaving a 5 mm keel width locally. Use the actual mate and marked removal shape as the stop.

Dress tiny A53/rear-spar wedges only where they prevent seating. Make small cuts, refit and stop when each joint seats without force. Preserve the surrounding 6 mm structure; measure any defect outside the shown patches before removing wood.

Check before continuing: All mates seat without force; each relief remains within its marked patch.

FITTING DETAIL

# A43 underside seats and curved rear relief

Top: actual A43 underside shows the marked bands on both rails. Lower: representative right-rail close-ups of the four source removal regions.

View the underside. Orange outlines are the exact source removal solids, confined to the four marked fore-aft bands. At the flat A25/A48 seats pare 1 mm from the underside, leaving 5 mm from the Z0 top face.

The A16/A04 reliefs follow curved contacts. Their removal solids span different depths; about 4.83 mm is a representative remaining section, not a whole-region thickness. Refit the actual former progressively. Keep all wood outside the highlighted removal shapes at its nominal 6 mm.

Check before continuing: Mark only highlighted contact patches; calipers and real mates confirm seating without full-frame thinning.

STEP 02

# Align the two keel halves

Orange identifies parts added or checked now. All airframe shapes are placed CAD geometry.
Take A62_F (front keel) and A62_A (aft keel). Front length is 529.070 mm; aft finished length is 482.650 mm. Stand their broad side faces in one plane on a straight jig, matching the top and bottom edge shapes. The butt seam is at Y100.

Use the A13/A43 frames loosely as an alignment check before bonding. Do not use glue to fill a misaligned step. The seam locates the halves; the two side laps in the next step carry the joint.

Check before continuing: A straightedge crosses the seam without a step or kink, and the dry frames seat.

FITTING DETAIL

# Keel lengths and local notch finishing

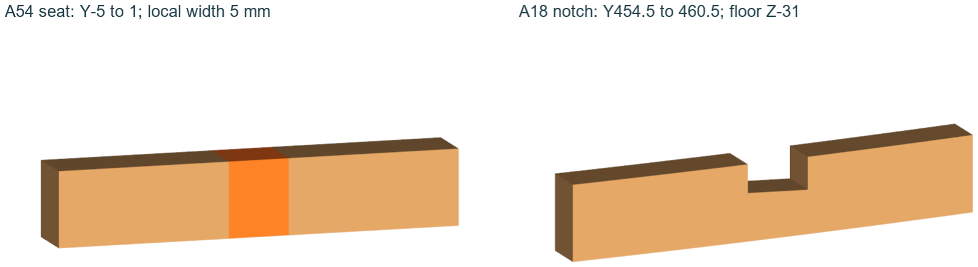
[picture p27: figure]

Close-ups use actual placed keel geometry and the A54 source removal solid. The aft notch floor remains a seating surface.
The front keel runs Y-429.070 to 100, length 529.070 mm. The aft keel runs Y100 to 582.650, length 482.650 mm. The complete current cut set already shortens the old aft projection by 13.015 mm. Keep the butt seam at Y100 and side laps at Y40-160.

At A54, Y-5 to 1, the front keel has shallow side relief to a local 5 mm width. This partial-depth operation cannot be laser through-cut. Follow the actual removal solid and mate; keep the neighbouring stock at 6 mm.

At A18, Y454.5-460.5, preserve the aft notch floor at Z-31. The 5 mm bottom tongue bears on that floor. Nominal keel notch and slot fit do not supply measured stock clearance; trial a representative fit coupon before bonding.

Check before continuing: Both halves and laps align; local front relief and aft notch seating pass on real wood.

STEP 03

# Bond both keel side laps

Orange identifies parts added or checked now. All airframe shapes are placed CAD geometry.
Fit A62_DL to the left broad side and A62_DR to the right side of the aligned keel. Each 120 mm lap spans Y40-160, giving 60 mm on each half. Align their lower edges with the keel at Z-41.714.

Apply the qualified wood adhesive to the complete mating faces. Clamp the halves and both laps flat in the jig. Wipe squeeze-out away from nearby slots. Keep the jig in place through clamp time and leave the joint unloaded through full cure.

If the keel is already joined, inspect both laps, the straight seam and the cured contact. Do not dismantle a sound joint to repeat this step.

Check before continuing: Both opposite laps are installed, fully bonded and straight; no loose edge, soft glue or split wood.

STEP 04

# Dry-fit the horizontal body frames

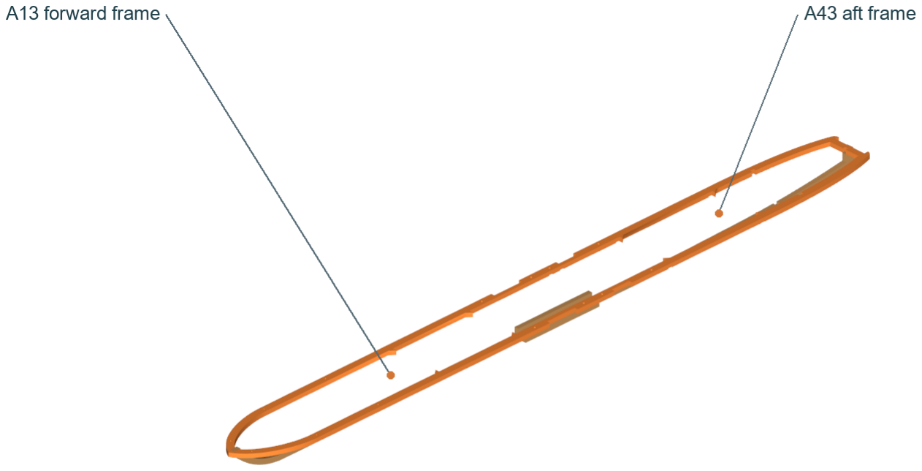
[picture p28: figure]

Orange identifies parts added or checked now. All airframe shapes are placed CAD geometry.
Fit A13 at the front and A43 at the rear onto the keel tabs. Their upper faces are the common Z0 plane. The rounded front of A13 points toward the nose; A43 runs toward the motor.

Keep the assembly supported so the thin frame members do not bow. Fit without glue now; the formers, gear-bay pieces, nose and tail carrier must all agree before you bond the body.

Check before continuing: The frames sit level on a straight keel, all tabs seat and the structure stays
square without force.

STEP 05

# Add the two forward body formers

Orange identifies parts added or checked now. All airframe shapes are placed CAD geometry.
A34 is the front ring former, with its forward face at Y-130. Fit its lower slot and frame contacts first. A54 is the centre ring former, with its forward face at Y-5: 125 mm aft of A34.

The former rings stand upright across the body. Keep their top arcs above the frame and their lower notches toward the keel. Check a square against each ring. Use the local A62_F relief from Step 1 if A54 will not seat.

Check before continuing: The two rings are upright, square to the centreline and 125 mm apart between forward faces.

STEP 06

# Add the two aft body formers

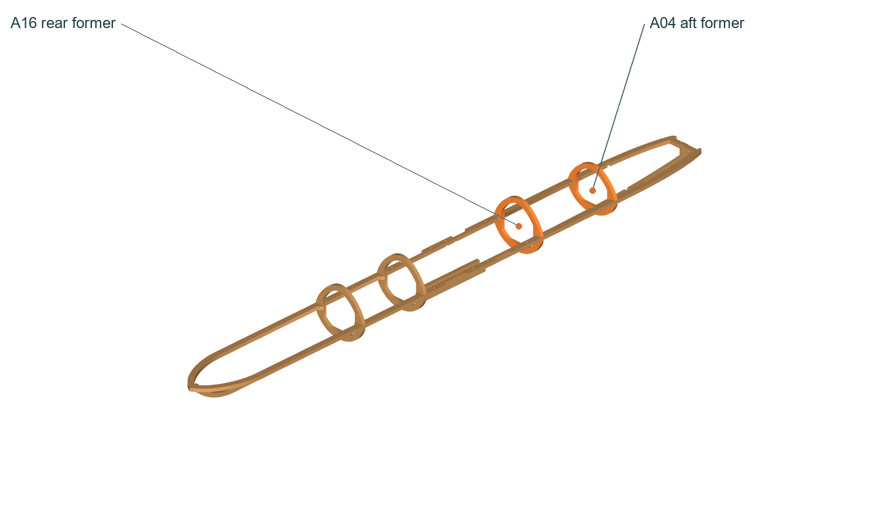
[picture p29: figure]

Orange identifies parts added or checked now. All airframe shapes are placed CAD geometry.
Fit A16 with its forward face at Y233.65, then A04 with its forward face at Y384.65. From the A34 forward face these distances are 363.65 and 514.65.

Keep each ring square and the top of A43 at Z0. If a former lifts A43, use only the documented local underside seat relief. Trial a lower foam wrap over the rings to see whether the body outline remains smooth.

Check before continuing: All four ring formers seat without twisting the body; left and right frame rails remain level.

STEP 07

# Fit the gear-bay pieces and tail bulkhead

Orange identifies parts added or checked now. All airframe shapes are placed CAD geometry.
Dry-fit A25 at Y125 and A48 at Y142.7, then A47 across their matching tabs. These three pieces stay in the wood skeleton even though purchased landing gear is deferred until after midsems.

Fit A18 tail-carrier bulkhead with its aft face at Y460.5. Its central opening clears the keel while its 5 mm bottom tongue seats on the keel notch floor at Z-31. Above Z16.697, the opposed outer receiver edges have 0.25 mm relief each, 0.5 mm total. The plate remains 6 mm thick; preserve the lower tongue and notch floor.

Leave the motor mount out until its separate fit step. Existing gear-bay structure is not proof of a bolt pattern or load capacity for the later gear.

Check before continuing: A25/A47/A48 sit flat and A18 is square; later gear and motor access remain open.

FITTING DETAIL

# Identify the tail-carrier receiver before glue

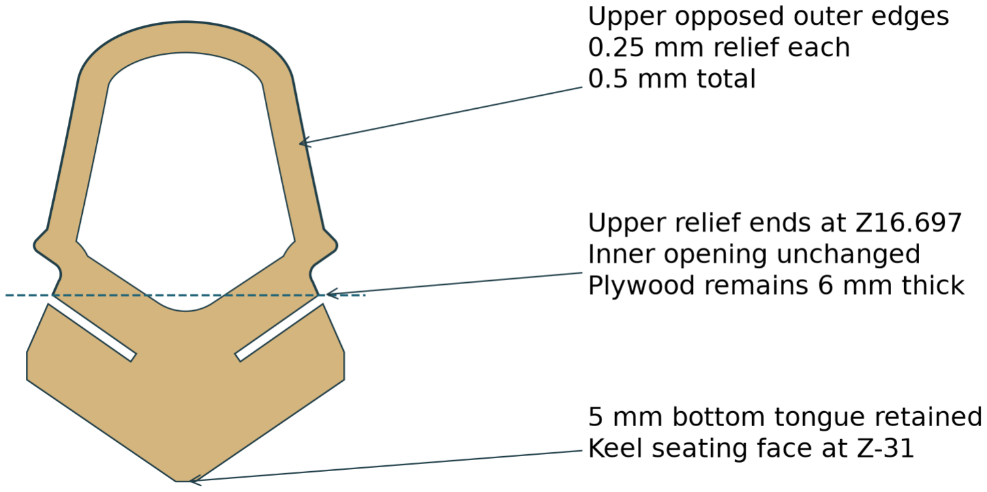
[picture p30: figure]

Actual A18 front view: the upper opposed external edges receive 0.25 mm relief per side. The lower tongue, inner opening and keel seat remain.
A18 is nominal 6 mm plywood. Its 0.5 mm total change is a perimeter allowance: 0.25 mm inward on each opposed upper external edge above Z16.697. The inner opening, lower arms, 5 mm bottom tongue and Z-31 seating face are unchanged.

The current adapted A12 file has a 6.3 mm axial receiver slot, nominally 0.15 mm per side of a 6 mm plate. This is separate from the upper perimeter relief. An older unadapted print has a local 2.5 mm slot and cannot take a 6 mm plate by contour relief alone. Measure the actual printed receiver and plywood.

The source matches when installed, but simple forward, aft, up and down insertion/removal movements are obstructed. Dry-fit the actual tilt/flex/order with the body open, without forced bending, before bonding A18 or A12. A successful installed CAD fit does not establish a removable shell.

Check before continuing: Actual print version, measured slot width and safe physical assembly order are established before glue.

STEP 08

# Trial the printed body parts, then bond the wood

Orange identifies parts added or checked now. All airframe shapes are placed CAD geometry.
Trial the owned A59/N1 nose, A06 centre fairing and A12 tail carrier against their frames before glue. A18/A12 have a clear installed fit in CAD, but straight insertion/removal is obstructed. Establish the real tilt/flex/assembly order with the body open before bonding either part. Stop if the receiver cannot seat without damage; do not force a shell over proud wood tabs.

The prints attach at their actual wood seating faces and sockets. A12 surrounds the tail bulkhead; A06 follows the centre formers and frame; A45/A55 roots seat against the wing structure and locate the two carbon rods. These contact patches carry load into the skeleton. Foam skin and tape can close seams but cannot replace the sound wood-to-print joints.

Mark which print contacts need the qualified print-to-wood adhesive. For the nose and access covers retain a removable path using tape/ties at sound frame contact, rather than sealing electronics inside. There is no dimensioned universal screw pattern for all shells.

When the complete dry body aligns, remove shells, bond wood contacts and clamp square through label clamp time and full cure. Then bond A12 to its A18 seating faces with the qualified print-to-wood adhesive and hold square until fully cured. Retain A06 serviceably with tape/ties at sound frame contact. Keep the nose removable, the motor mount out and the body open.

Check before continuing: The cured wood is straight; shells seat by hand and motor, battery and USB/SD access can be reached.

STEP 09

# Align each rear wing spar

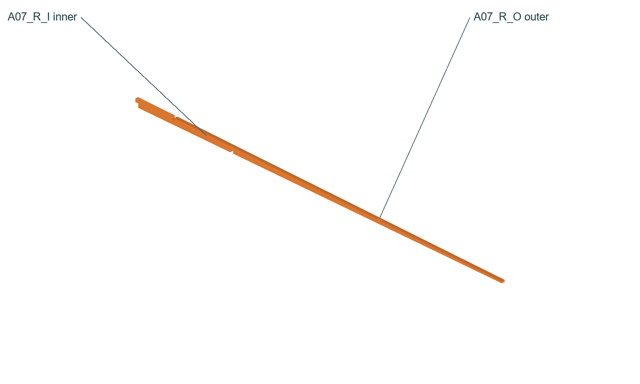
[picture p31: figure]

Orange identifies parts added or checked now. All airframe shapes are placed CAD geometry.
On the right, align A07_R_I (inner section) with A07_R_O (outer section). Their seam is at X360. On the left use A07_L_I and A07_L_O, with the mirrored seam at X-360.

Lay each spar broad face on a flat jig. Keep its notches facing the matching ribs. Trial-fit the ribs before glue so a reversed half is caught now.

Check before continuing: Each spar is straight across its seam and its notches match the correct-side ribs.

STEP 10

# Bond both face laps on each spar

Orange identifies parts added or checked now. All airframe shapes are placed CAD geometry.
Fit A07_R_D1 and A07_R_D2 to opposite broad faces of the right spar. Each 100 mm lap covers X310-410, giving 50 mm per half. Repeat with A07_L_D1/D2 on the left.

Bond full contact with the qualified wood adhesive. Clamp straight and keep glue out of rib notches. Both laps are structural pieces; a rigid-looking butt joint is not a reason to omit one. Leave unloaded until full cure.

Check before continuing: Both spars have two opposite cured laps, straight edges and open rib seats.

STEP 11

# Build the right wing with its reinforced plywood rib

Current reinforced plywood outer rib in the actual wing frame. Lower detail shows its closed front seat and 3 mm roof; rods enter axially before skin closure.

Lay out A05_R front spar, joined A07_R rear spar, A35_R inner rib, A24_R middle rib and A01_R rear-rod support rib. Use the current reinforced nominal 6 mm plywood A44_R at the outer station.

Ribs run fore-aft, rounded noses toward the leading edge: inner station about X53, middle X250 and outer X490. A01_R supports the rear rod near X130. Its tiny lower front toe and upper rear shelf are removed; fixture A07 at its original height while bonding the broad spar contact faces.

A44 has a 3 mm servo-bay roof and a closed front-rod seat with a 3 mm surrounding ring. The leading fine tip is shortened 3.632 mm; keep the complete original trailing tip. Laser stock adds a sacrificial underside tail band to maintain a 3 mm cutting web. Pare only that underside allowance to the finished source taper before fitting A53 or the skin. Trial the actual servo and skins; relieve upper and lower inner foam locally near the closed front seat on each wing. Keep outer paper intact.

Keep the full trailing tip and its A53 contact footprint; never shorten it to remove the sacrificial band. The three inherited small A44 holes are omitted from the laser CUT profile. Mark and hand-drill only after the actual servo tabs/retainer fit is established; drilling can recreate thin webs. Dry-fit the whole frame and rod path, then bond the full wood contacts with tested wood adhesive and cure without twist.

Check before continuing: Spar height and airfoil attitude match the jig; servo access, local skin relief and axial rod path are clear.

FITTING DETAIL

# A01 rod support and spar-height jig

Actual final A01 profile and mating spar contacts. The tiny removed toe/shelf no longer provides a height stop.
A01_L/R retain the robust body and exact 5 mm rear-rod hole at Y100.500, Z15.070. Only the very small 0.036 mm lower front toe and 0.141 mm upper rear shelf are removed along the existing spar contact planes.

The rear shelf no longer registers A07 height. Keep the rear spar in the airfoil jig and bond the broad vertical contact faces: about 64.677 mm2 against A05 and 50.662 mm2 against A07. The rod wall remains about 4.408 mm; this change does not add a skin bulge or require a new foam recess.

Dry-fit A01 from above into the open frame, then feed the rear rod axially before closing the skins. Preserve its source hole and spar contacts; a 5 mm nominal rod needs actual-fit confirmation.

Check before continuing: Rear spar stays at the jig height through cure, broad faces bond and the actual rod feeds axially.

STEP 12

# Build the left wing and compare both sides

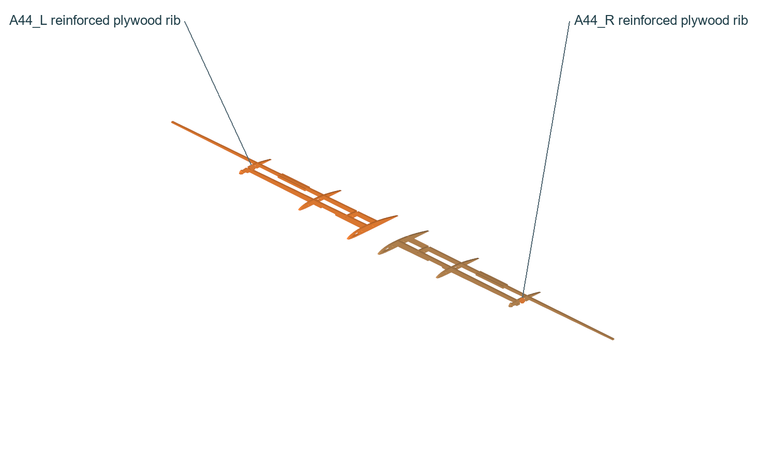
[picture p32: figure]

Orange identifies parts added or checked now. All airframe shapes are placed CAD geometry.
Repeat Step 11 with A05_L, A07_L, A35_L, A24_L, A01_L and reinforced plywood A44_L. This is a mirror. Match the servo pockets, closed rod seats and control attachments to their correct sides.

Compare both frames on the same flat jig before adhesive cures: rib stations, leading edges, spar joints, root faces and twist. A01 keeps its exact 5 mm rear-rod hole; its trimmed shelf no longer sets spar height, so retain the jig through cure.

Trial each outer skin and fixed hinge rail. Relieve upper and lower inner foam only where reinforced A44 material touches them near the front seat, on both wings. Preserve outer paper and the matching airfoil attitude; do not shorten one wing to conceal a mistaken fit.

Check before continuing: Both wings have matching rib spacing, spar height, airfoil attitude and clear axial rod insertion.

FITTING DETAIL

# Pare the A44 tail underside before assembly

Actual stock and finished tail profiles. Orange is the exact secondary removal allowance; brown is retained. The full Y166.859 trailing tip remains.
The full-length trailing tip carries the source A53 contact and matching skin taper. The laser blank extends below that thin taper to keep at least a 3 mm vertical web during cutting. This extra underside wood is temporary cutting stock.

With the rib supported flat, transfer the finished side profile, then pare and sand only the orange underside allowance between approximately Y152.458 and Y166.859. Refit against the actual A53/skin progressively. Keep the complete trailing tip; do not shorten it or remove the upper foil surface.

Finish both mirrored ribs before bonding A53, fitting skins or closing the wing. The closed front-rod seat, 3 mm surrounding ring, 3 mm servo-bay roof and manual small-hole drilling remain part of the same rib.

Check before continuing: Both underside tails match the finished taper; full tip, A53 contact and skin fit remain intact before bonding.

FITTING DETAIL

# A44 paring templates at actual size

Print only this page at 100% / Actual Size. Measure the 25 mm bar before tracing; do not use Fit to Page. The two profiles are 113.394 mm long, from Y53.465 to Y166.859.

Black is the finished outline; orange underside is temporary laser stock to pare away. Preserve the full trailing tip. These thin finished profiles are hand-finishing templates, not laser cutting patterns.

A44_L - 6 mm plywood; full trailing tip retained

Finished length 113.394 mm. Trace underside taper; do not shorten the tip.

A44_R - 6 mm plywood; full trailing tip retained

Finished length 113.394 mm. Trace underside taper; do not shorten the tip.

25 mm calibration bar - confirm with a ruler on the actual print.

FITTING DETAIL

# Reinforced A44 seats and skin clearance

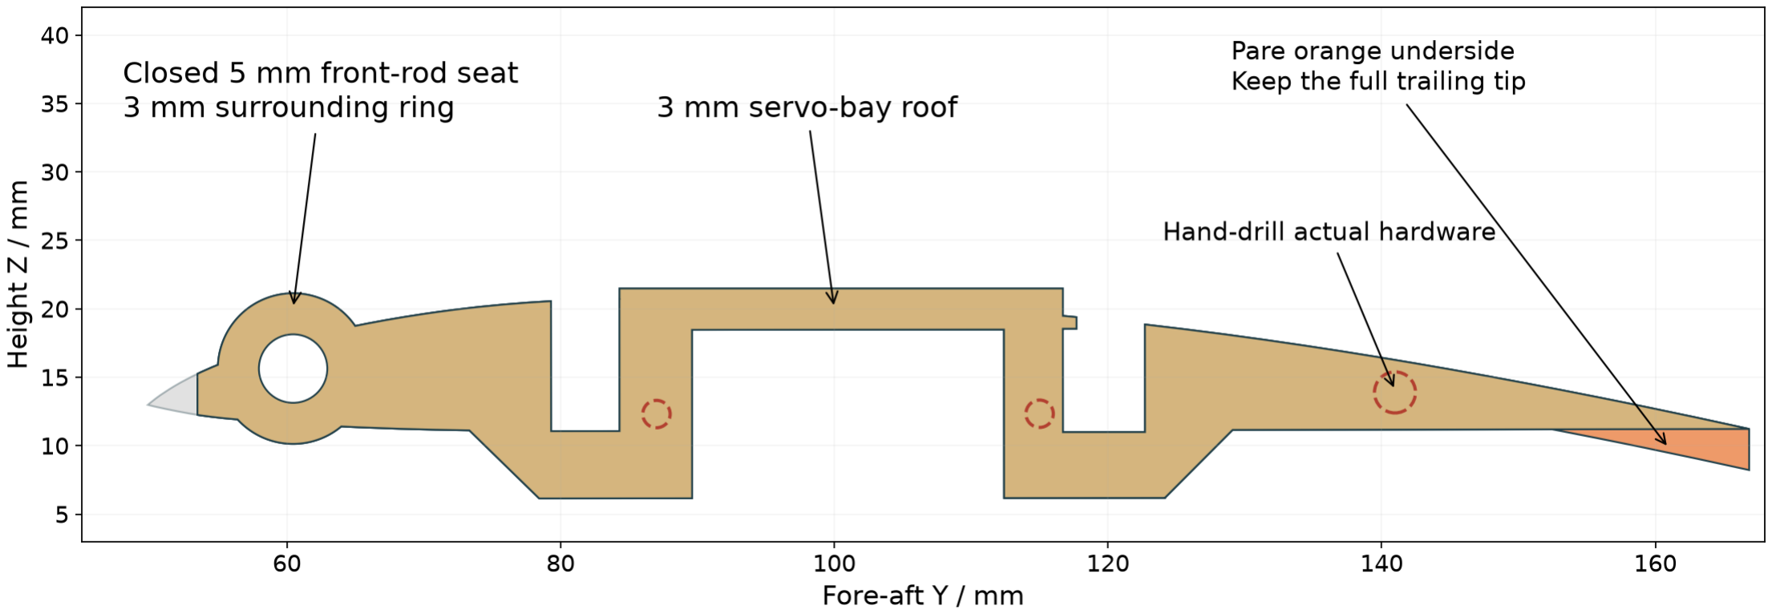
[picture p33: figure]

Current right-rib profile: orange tail underside is sacrificial laser stock, brown is the finished taper. Preserve the full trailing tip. Dashed small-hole datums are hand-drill references; the left rib is mirrored in installed thickness.
Use the reinforced nominal 6 mm plywood pair. The front seat is closed around the source 5 mm rod axis; it has a 3 mm surrounding ring. The servo-bay roof is also 3 mm. Only the leading fine tip is shortened 3.632 mm. The original trailing tip is retained to Y166.859, giving 113.394 mm fore-aft length. The laser blank has sacrificial underside tail stock; pare that allowance to the finished taper before A53 or skin fitting.

Both wings need local upper and lower inner-foam relief near the front rod seat where reinforced material reaches the skin. Preserve outer paper. Insert the front rod axially through the closed seats before closure, after the wing/root dry-fit.

Three inherited small hardware holes are omitted from laser cutting. Mark and manually drill against the actual servo tabs/retainer only after checking edge distances. An omitted hole is not proof that any chosen screw fits or that thin wood restored by drilling will carry load.

Check before continuing: Closed seat, 3 mm roof, both skin reliefs, axial rod path and actual servo retention pass before closure.

STEP 13

# Fit both roots and the two whole carbon rods

Orange identifies parts added or checked now. All airframe shapes are placed CAD geometry.
Fit A55 left root and A45 right root with the complete body and both wing frames supported. Slide the front rod through the nominal 5.2 mm printed bores and mating wood seats at Y60.454/Z15.632. Slide the rear rod at Y100.500/Z15.070.

Each rod is solid carbon, 5 mm diameter and 1000 mm long, centred from X-500 to +500. Keep both whole; do not cut or butt-join them at the body. The reinforced A44 front-rod seat is closed. Insert the rod axially before outer-wing skin closure; it cannot be dropped into the seat from above. Keep both rod paths accessible during dry-fit.

Trial the actual rods, roots and wood simultaneously. Finish a bore locally only enough for a snug fit; do not scale a root. Mark the loaded root-to-wood contact and bond only after a qualified offcut joint and full dry fit.

Before covering, prove that neither a wing nor a rod can move out spanwise. The source does not define a fully qualified removable locking system. A friction fit alone is insufficient: hold this stage for a documented positive restraint and physical pull/load check if the installed bonded arrangement cannot resist escape.

Check before continuing: Rods remain whole; both roots seat without cracks; wings and rods have demonstrated restraint against escape.

STEP 14

# Install the fixed aileron rails and endplates

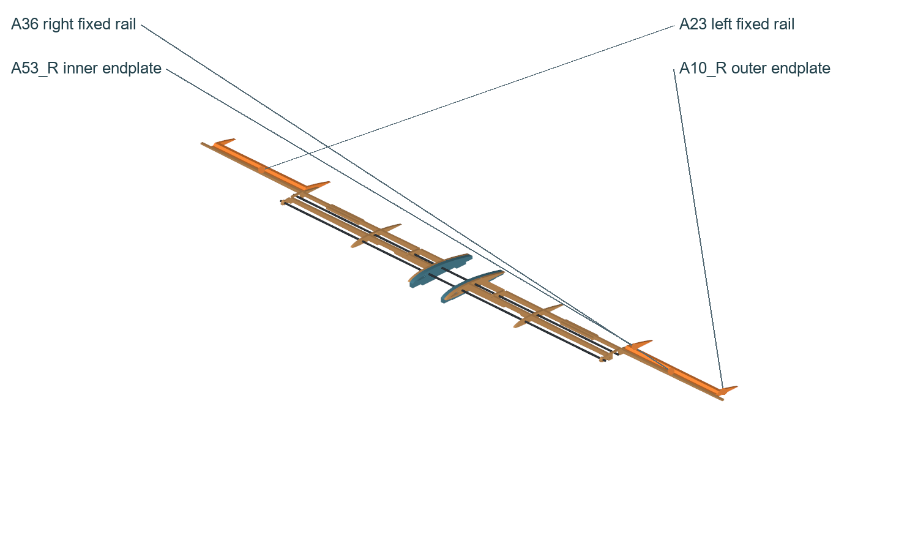
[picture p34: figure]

Orange identifies parts added or checked now. All airframe shapes are placed CAD geometry.
Right side: fit A36 fixed hinge rail with A53_R inner wooden endplate and A10_R outer endplate. Left side: A23 with A53_L and A10_L. Trial the corresponding moving aileron before bonding the fixed pieces.

The endplates lie beyond the moving surface ends, not inside its free span. Preserve their pivot-support material. The inner A53 datum remains about X493 on the right and its mirror on the left. Keep the printed rail aligned with the common hinge line.

Use qualified wood adhesive at wood contacts and qualified print-to-wood adhesive at the fixed rail contact. Keep all hinge pilots free of glue and leave space for the captive pin heads.

Check before continuing: Both rails are fixed and straight; moving ailerons can fit between their endplates without being pinched.

STEP 15

# Fit the unchanged ailerons and captive pins

Orange identifies parts added or checked now. All airframe shapes are placed CAD geometry.

Use A21 on the right and A11 on the left. These are the existing unmodified print geometries supplied again because they were missed. Use their 2 mm common-axis pilots, not a full-length hinge shaft.

Measure the actual spoke/pin diameter. Align the two end pilots and finish them carefully to a smooth rotating fit. Each aileron uses two short end pins. Keep adhesive out of the bearing and keep the surface clear of its fixed rail.

Make bent L heads from suitable spoke offcuts, and trap each head against the wooden endplate with reinforced tape or a tie. The head must remain clear of the moving surface and cannot slide out. Test the restraint in both directions; replace tape if it peels or allows pin movement.

Check before continuing: Both ailerons move freely; four end pins are positively captive without bearing glue or hinge rub.

STEP 16

# Mount wing servos, horns and pushrods

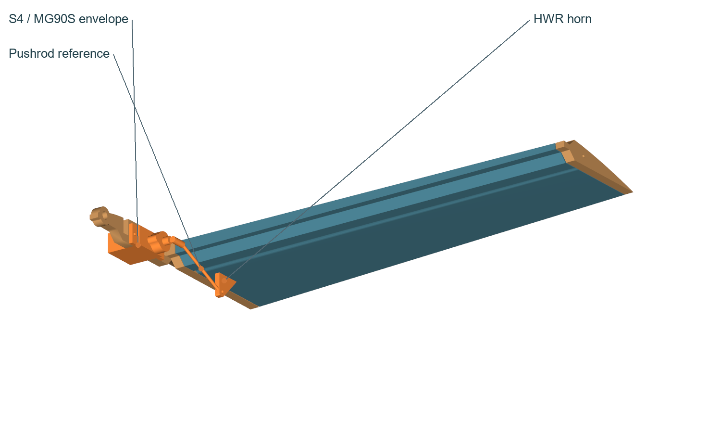
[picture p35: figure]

Actual airframe, horns and source servo envelopes. Arm and pushrod cylinders illustrate a route; set length and captive bends on the real parts.

Fit an MG90S at each reinforced plywood outer-rib pocket: S3 left and S4 right. Before fitting arms, keep flight battery/ESC disconnected and prop removed. Connect one servo to a standalone tester: verified signal to signal, positive to regulated 5 V and ground to ground, following its keyed contact view. Select neutral mode; then fit the factory arm near a right angle to the pushrod and retain its supplied centre screw.

If no verified 5 V tester is available, leave arms off and skins open. Complete the bench power/configuration checks in Steps 26-29 and 30-31, command neutral from the configured FC, then return here and fit the arms. Do not close wings at Step 22 before this dependency and actual full-travel tests pass.

Seat the real mounting tabs against the actual rib. Use the servo supplied mounting hardware only after matching tab holes and screw/pilot dimensions; mark and hand-drill the omitted A44 mounting holes only after checking actual tab spacing and safe pilot/edge distances. The source servo envelope does not prove MG90S tab fit. If the tabs cannot be securely captured, hold this joint for measured fitting.

Fit HWL/HWR to their respective moving ailerons at the CAD contact. Abrade only the bond patch, clean and use the qualified adhesive through full cure. Horn pilot holes are nominal 2 mm for the pushrod, not servo mounting holes.

Trial one bicycle-spoke pushrod per wing with captive articulating ends. Measure its diameter, thread, arm hole and horn hole before cutting. The pictured 10 mm arm radius and straight rod are references, not a cut-length instruction. Leave all adjusters and the servo arm screw reachable.

Check before continuing: Servos and horns cannot shift under light control load; linkage moves without over-centre motion, rub or pin escape.

STEP 17

# Form and fit the fixed upright V-tail

Upper: evolving body assembly. Lower: rear close-up shows both fixed tails seated symmetrically in the actual A12 carrier.

FW05 becomes the right fixed tail A57; FW06 becomes the left fixed tail A22. Each is one whole folded skin including its root collar. Match the source tail profile and trial the root against A12.

Precurve and fold progressively, keeping the outer paper intact. Remove or compress inner foam only where the fold and root need relief. Test on an offcut first. Dry-fit both fixed tails before bonding so their angles and trailing edges are symmetric.

Bond the tail skin and its A12 seating patch with a tested foam-safe adhesive that also suits the printed carrier where they contact. Support both tails at the CAD angles through full cure; do not force a warped tail into a socket.

Check before continuing: Tail roots seat in A12, both halves angle upward symmetrically and no paper is torn or core crushed.

STEP 18

# Laminate the moving tail controls and hinge them

Orange identifies parts added or checked now. All airframe shapes are placed CAD geometry.

FW12 right uses two 5 mm blanks to make A41; FW13 left uses two to make A60. Bond matching layers flat with the qualified foam adhesive. Keep supported through full cure, then finish the marked outline, trim allowance and rounded leading edge.

Hold each moving surface at neutral next to the fixed trailing edge. Apply reinforced tape to both faces and press the exposed tape together across the gap to form a flexible web. Keep the gap free from a hard glue bridge.

Trial movement roughly 15 degrees each way as a basic bench fit check, not a flight-qualified throw. The web must not peel, bind or allow fore-aft slop. Stop and remake a hinge that tears the paper or cannot move symmetrically.

Check before continuing: Both laminated controls are flat, retained by sound flexible webs and move freely in both directions.

STEP 19

# Fit the two tail servos and backed horns

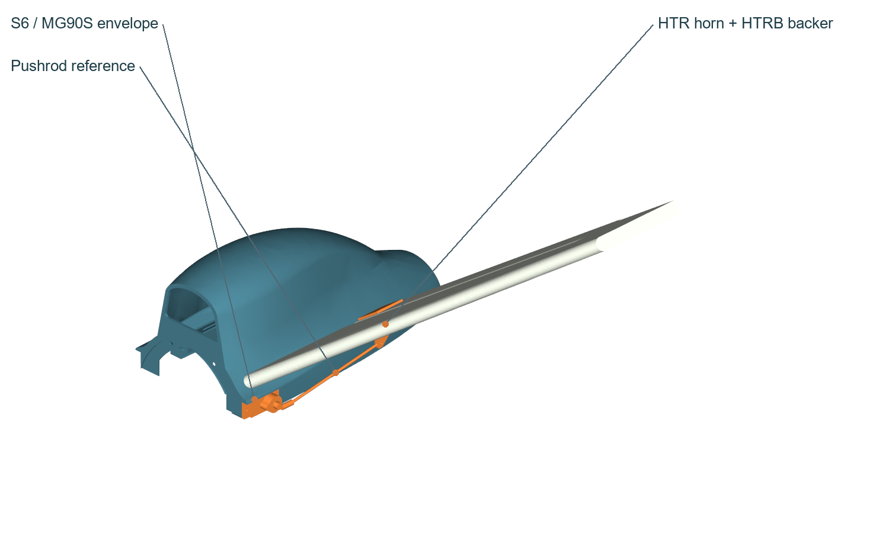
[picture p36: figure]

Right-side tail close-up; mirror the hardware for the left. Source servo envelope and schematic rod route require actual tab and linkage fitting.

S5 is the left tail MG90S and S6 the right. The source shaft targets are X-63.85/+63.85, Y411.10, Z6.215. They sit beside the original tail roots, with arms, centre screws and pushrod adjustments accessible.

Use the verified 5 V tester/neutral procedure in Step 16 before fitting the factory arms and retaining the arm screws. With no tester, leave arms off and return after the FC power/configuration checks; keep the skins open. Trial actual body/tabs, and use matching supplied hardware at sound mounting contact only. Hold a joint if the envelope does not securely seat the real unit.

Fit HTL/HTR horns to the left/right moving controls with HTLB/HTRB backing plates against the opposite foam face. The backers spread local load. Fit and cure the tested foam/print bond without crushing the core. Do not trust a horn glued to unsupported paper.

Use two more bicycle spokes as tail pushrods with measured, captive articulating ends. Cut only after full neutral and combined pitch/yaw movement has been tested. Keep rods clear of the carrier and motor wiring.

Check before continuing: Both tail servo mounts, horns and backers remain secure; every combined endpoint moves without rubbing or foam peel.

STEP 20

# Check the complete open structure

Orange identifies parts added or checked now. All airframe shapes are placed CAD geometry.
Put the body, both wings, fixed tails and controls together before any skin is glued closed. Confirm all wood laps are cured, printed root contacts are sound and rods and hinge pins are retained.

Move each control through full intended bench travel while supporting the airframe. Check rubbing, play, horn peel, servo buzz and an arm approaching over-centre. Correct the mechanical cause before limiting travel in software.

Run each wing servo cable to its root with enough slack for wing handling. Use smooth-edge tape/tie supports on fixed structure, avoiding hinges, pushrods and rod movement. Plan removable wing connectors and label S3 left / S4 right at both ends. Run tail cables forward along the frame, clear of the motor and driver path.

Leave an accessible route to the servo mounting and arm screws, connector separation points and tail adjusters. If you cannot service one of them after skinning, change the access plan now.

Check before continuing: Four controls move freely, every connector is labelled, and all restraints and service points can be inspected.

STEP 21

# Form the inner wing skins you already cut

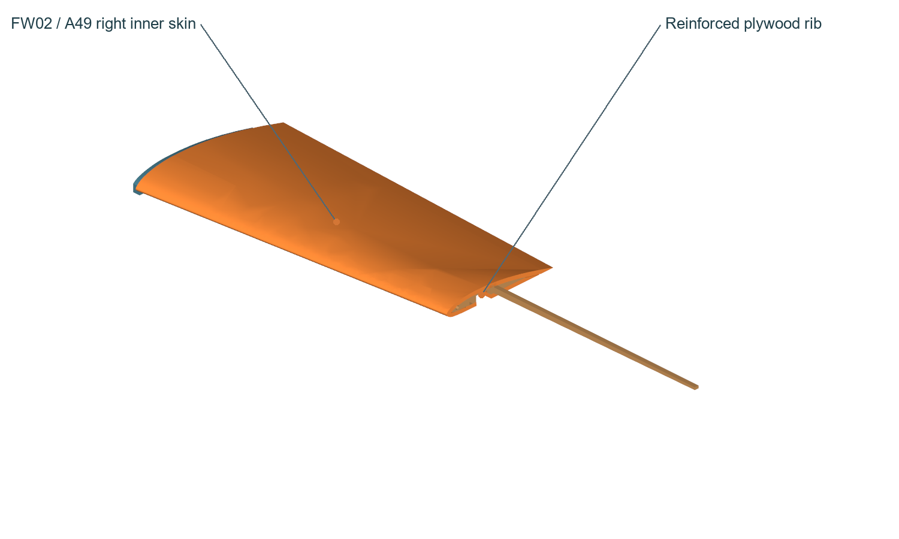
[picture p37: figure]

Orange identifies parts added or checked now. All airframe shapes are placed CAD geometry.

FW02 is the right inner skin (A49) and FW01 the left (A52). If each is already a whole skin, keep it intact. If supplied as ROOT/TIP cuts, butt the matching straight edges on a flat board, bond the core with foam-safe glue and tape across the outer paper. Cure the join before curving.

Mark the inside, leading edge and part ID from the cut map. Curve progressively over the actual inner wing frame; keep the outer paper continuous. Only relieve the inner core where a rib, rod or fold interferes. The source fold marks are hand references, not extra through-cuts.

Dry-fit the root, inner/middle ribs and rods together. Hold the airfoil without twisting it. Do not hide a broken spar or force a poor root fit under the skin.

Check before continuing: Each skin matches its side, forms without buckles and clears the whole rods and root without forcing.

STEP 22

# Dry-fit outer skins and keep access open

Actual outer skin shown in its final position, held temporarily for fit. Permanent closure waits for powered controls and supply checks.
FW03 is the right outer skin A38 and FW04 the left outer skin A27. Trial around the completed ribs, fixed rails, servos and controls. Retain the documented inner-foam relief against A10_R/A53_R and their left mates. Relieve upper and lower inner foam locally near the closed front rod seat on both wings; preserve outer paper. Rods must already be inserted axially before closure.

Confirm rod/root retention, captive aileron pins, horn bond and servo mounting. Route the servo cable, test its connector and leave the servo arm accessible. Keep an inspectable/removable seam or opening at each servo rather than permanently burying it.

Hold the skins with removable tape now. Leave them unbonded until FC configuration, actual Vx/Vx2 loaded-servo movement, direction and failsafe tests pass. Final wing bonding is in Step 34; keep tape clear of the moving hinges.

Check before continuing: Both wings dry-fit symmetrically with smooth cable exits; all joints, servos and connectors remain accessible.

STEP 23

# Place and restrain the battery and electronics

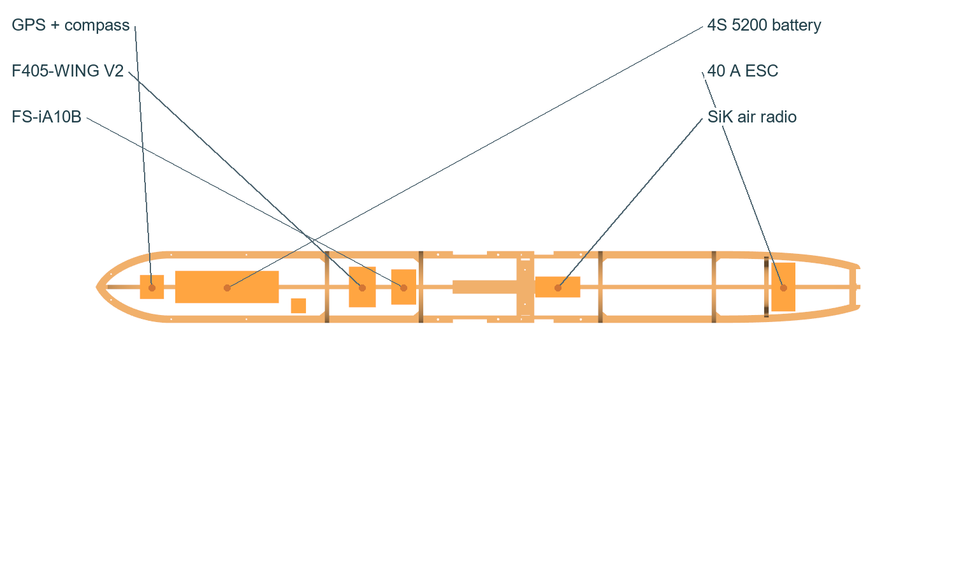
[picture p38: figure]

Top view of actual frame with nominal device envelopes. Final positions follow real connector access, interference tests and measured balance.

Start with the battery on sound A13 wood in the forward bay; the old centre target Y-260 is only a trial location. Use an insulating nonslip pad and two independent straps around the existing frame and battery. Round or pad sharp contact edges. Adhesive may locate the pad but must not be the only pack restraint.

Fit F405-WING V2 with known arrow/orientation on a suitable insulated vibration pad near the forward centre body. Leave USB, microSD and all plugs reachable. Place FS-iA10B nearby with separated antenna tips away from carbon and motor-current wiring.

Place the SiK AIR unit in the middle/aft body where its antenna and serial plug remain serviceable. Mount ReadytoSky 40A ESC aft on sound frame with ties/tape, cooling surface exposed and motor wires secured. Check its lead-length guidance before adding battery-wire length.

These drawn device boxes are nominal envelopes placed on real CAD, not exact device models or a fit certification. Trial the real leads, straps, cover and removal path. The old analysis already shows battery positions near Y-192 can collide with A34; do not force that position to chase a predicted CG.

Check before continuing: Battery cannot slip and can be removed unplugged; board USB/SD, receiver plug, radio and ESC remain accessible.

STEP 24

# Place GPS, pitot and airspeed tubes

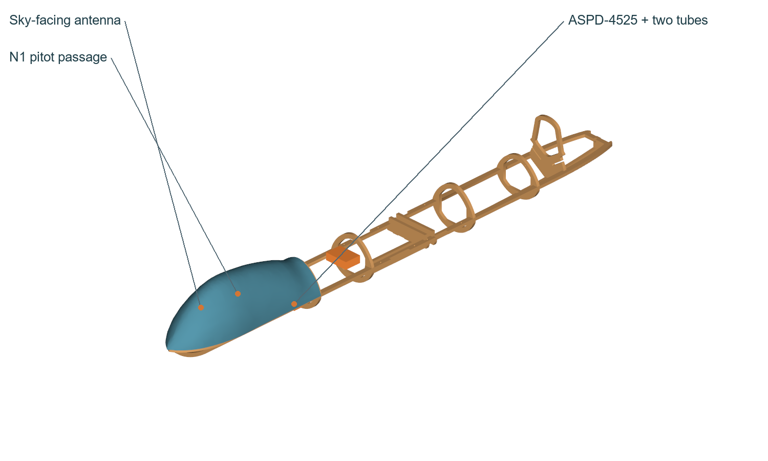
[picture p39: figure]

Orange identifies parts added or checked now. All airframe shapes are placed CAD geometry.
Place the documented M9N-5883 GPS/compass with antenna face skyward in the upper nose region. Keep the compass at least 100 mm from power wiring, ESC, motor and ferrous hardware as the manufacturer recommends; centre-to-centre box spacing alone is insufficient. Verify the real clearance to leads.

Reuse the owned A59/N1 nose. With electronics and battery removed, offer up the actual pitot and mark a forward-facing passage that clears the shell, frame and nose removal path. Drill a controlled pilot and enlarge only for a snug tube/support fit. Do not copy a guessed CAD hole location.

Secure the pitot to sound support with tape/ties without covering sensing ports. Lead both silicone tubes to ASPD-4525 near the forward body; support gently, avoid kinks and leave the sensor ports reachable. Identify total/static ports from the actual sensor/manual.

The pressure sensor, GPS and radio must match their documented models before connector pin order is used. If a label differs, stop that connection and identify its exact manual; continue the other mechanical work.

Check before continuing: Nose removal does not pull the tubes; sensing holes remain open and compass separation is measured.

STEP 25

# Dry-fit the plywood motor firewall blank

Actual no-motor-hole plywood A26 in the rear frame. The nominal digital insertion route is clear; real stock fit and cured joint strength still need physical proof.
Use the current nominal 6 mm plywood A26 no-motor-hole blank. It retains the source shaft/keyhole opening and smooth 6 mm-height flank seats. No motor screw pattern is laser cut; the actual EMAX base must set the drill pattern.

Insert the mount axially from the rear with the motor removed. A43 blocks a drop-in vertical approach. Keep the aft keel flush with the firewall aft face at Y582.650; the current A62_A cut outline already removes the former 13.015 mm rear projection.

Trial A26 on actual A43/A62_A and check flatness, slot fit, A12 clearance and driver access. The central slot and keel are both nominally 6 mm, so actual stock, kerf and adhesive determine fit. A43 does not fully fill the flank notches; collision-free CAD does not prove a complete tongue joint.

Physical mount mismatch has not been confirmed. If a seat catches, identify the exact contact and measure it before local fitting. Test the actual wood adhesive/contact on an offcut, bond only after the dry-fit and hold square through full cure. Keep the shell open for real motor checks.

Check before continuing: Mount seats by the rear axial route, actual contact and driver access are identified, and no unmeasured motor holes are drilled.

MOTOR DETAIL

# Motor fitting detail and manual drilling

Current trimmed keel and plywood firewall blank. Lower: the source shaft/keyhole relief remains; motor bolt holes are intentionally absent.

Check the documented EMAX ECO II 2807 1300KV label on the real motor. Its official drawing specifies four M3 threads on a 19 mm pitch-circle diameter, equivalent to 13.435 mm adjacent square spacing. This is a reference, not permission to drill a guessed pattern.

Offer the actual motor base or its verified template to the blank at shaft centre X approximately 0, Z-2.5. Confirm shaft/boss relief, bell/wire clearance, flange seating and full driver access, then mark and hand-drill the matching clearance holes. Keep the propeller removed.

Measure the full screw/washer/6 mm plywood stack, head diameter and safe M3 thread depth. Supplied M3x8/M3x10 lengths are not automatically correct. Screws must clamp without bottoming or reaching windings; any washer must sit fully supported and clear the bell.

The aft keel ends flush at Y582.650 in the current cut set. For an older blank ending at Y595.665, remove only its 13.015 mm aft projection, keeping the joint and all wood forward of the firewall. Qualify actual mount contact, screw retention, thrust/torque, heat and vibration progressively before flight.

Check before continuing: Real motor pattern, boss seating, safe screw engagement and driver approach pass before fastening or powered testing.

STEP 26

# Connect high-current power with the prop off

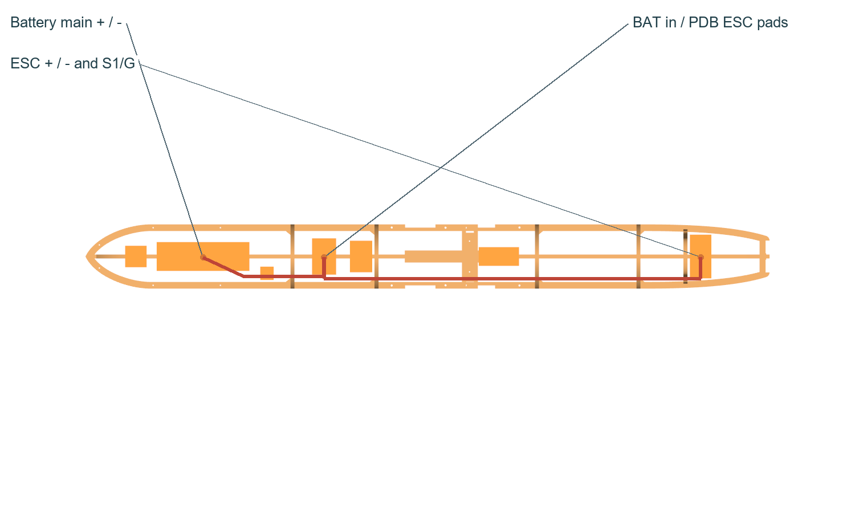
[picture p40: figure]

Red traces show power routing on the real frame. Match the actual wire lengths and service loops; device boxes are nominal envelopes.
Keep the GenX RKI-4897 4S 5200 mAh pack disconnected. Its nominal voltage is 14.8 V and full voltage 16.8 V. Check the actual matching high-current main connector, positive and negative; the balance plug is for the charger, not the FC.

Connect the battery main positive/negative to F405-WING V2 BAT input with the verified connector and suitable rated wiring. Connect ESC thick positive/negative to the board PDB ESC power pads, following their actual labels. Connect the three motor phase wires to the ESC and restrain them clear of the bell and controls.

Connect ESC throttle signal to S1 and its control ground to G. The ReadytoSky family has a documented BEC despite some OPTO titles: inspect and meter your unit. If its red BEC wire is live, isolate and insulate that positive so it is not accidentally paralleled with onboard servo power.

Insulate every joint and support wires at frame ties without crushing insulation. With the battery still unplugged, check continuity, shorts, polarity and connector key orientation with a multimeter. Route high-current wiring away from compass, receiver antennas and sensor cables.

Check before continuing: Polarity and insulation pass; ESC BEC handling is verified; no motor wire can reach a moving part.

CONNECTIONS

# Power and motor connection map

From | To / net | Check
Battery main + / - | FC BAT + / GND | 4S 14.8 V nominal, 16.8 V full; connector polarity
FC/PDB ESC + / - | ESC DC + / - | Wire and pad rating; continuity; insulated joints
ESC three phase leads | Motor three phase leads | Prop off; secure away from rotating bell
FC S1 / G | ESC throttle signal / ground | Live ESC BEC positive isolated if onboard BEC used
FC Vx set to 5 V | S3 and S4 servo + rail | Measure before plugging in servos
FC Vx bridge to Vx2 | S5 / S6 servo + rail; S7 later | Vx2 is unpowered without bridge or separate supply
FC S3 / S4 / S5 / S6 | Each servo signal | Each servo also has +5 V and common GND

Check before continuing: Use actual board pad marks and actual keyed contacts; wire colour alone does not establish polarity.

STEP 27

# Connect servo power and receiver

Amber traces show fixed-frame harness routes from the four source servo locations to the FC. Leave labelled detachable connectors at wing roots. S7 is deferred.
Set the F405-WING V2 servo BEC Vx to 5 V for MG90S. Bridge Vx to Vx2 when using the onboard supply for the tail servos. Vx powers S3/S4; Vx2 powers S5/S6 and later S7. Measure both rails before connecting servo plugs.

Connect each servo lead signal, positive and ground to its matching output: S3 left aileron, S4 right aileron, S5 left V-tail, S6 right V-tail. Confirm the actual plug orientation. Keep S7 steering unplugged until gear is fitted after midsems.

Connect FS-iA10B servo-iBUS output signal to FC RX2, plus rated peripheral 5 V and common GND. Do not use the receiver SENS port. Label the wing connectors on both ends; protect their latch/release access.

Onboard Vx is rated 5 A continuous and 6 A peak; peripheral 5 V is rated 2 A total. Test actual simultaneous servo and accessory load before closing. Add up rated accessory consumption rather than assuming every 5 V connector has a separate supply.

Check before continuing: Each plug polarity and side is checked; Vx and Vx2 read 5 V; receiver servo-iBUS is on RX2.

STEP 28

# Connect sensors and the SiK air radio

Teal traces show sensor/receiver/radio routes on the real frame. Keep signal routes clear of high-current wiring; final plug orientation comes from the actual devices.
For documented M9N-5883, connect GPS TX to FC RX3 and GPS RX to FC TX3, plus rated 5 V/GND. Connect compass SDA to DA2 and SCL to CL2. TX crosses to RX; do not join TX to TX.

For documented ASPD-4525, connect its SDA to DA2 and SCL to CL2 on the same I2C2 bus, plus 5 V/GND. Its manufacturer GH order is 5V, SCL, SDA, GND. Check connector view/key on the actual device before fitting it; do not infer numbering from the aircraft picture.

Connect RKI-1980 SiK AIR TX to FC RX1 and AIR RX to FC TX1, with verified 5 V and GND. A standard 3DR GH-6 harness uses 1=5V, 2=FC TX1, 3=FC RX1, 4/5=CTS/RTS unused here, 6=GND; verify key orientation and continuity of your owned harness.

The black USB GROUND radio plugs into the computer, never into aircraft UART pads. Keep signal grounds common. Use a verified splitter/parallel harness for shared I2C; insulate unused contacts and support solder joints.

Check before continuing: Every labelled net reaches its intended device, no supply/signal contact is swapped, and I2C harness continuity passes.

CONNECTIONS

# Receiver, sensor and radio map

Device pin / net | F405-WING V2 pad | Notes
FS-iA10B servo-iBUS signal | RX2 | BRD_ALT_CONFIG=0; not SENS
Receiver + / GND | Peripheral 5V / GND | Check actual keyed harness
M9N GPS TX / RX | RX3 / TX3 | Cross serial directions
M9N compass SDA / SCL | DA2 / CL2 | I2C2 shared with airspeed
ASPD-4525 SDA / SCL | DA2 / CL2 | GH order 5V, SCL, SDA, GND
GPS and ASPD power / GND | Peripheral 5V / GND | 2 A total peripheral BEC budget
SiK AIR TX / RX | RX1 / TX1 | Cross serial; verify real harness
SiK AIR power / GND | Verified 5V / GND | GROUND USB unit stays at computer
Pitot total / static pressure | ASPD total / static ports | Two tubes; identify real ports; no kinks

Check before continuing: If any received device differs from the named model, identify its manual before connecting it.

## REAPER - COMPLETE ELECTRONICS CONNECTION MAP

One diagram for the owned parts. This is a functional net map, not a physical connector-position drawing.

### 1 HIGH-CURRENT POWER + MOTOR

GENX RKI-4897 4S

Main lead: positive + negative

Yellow XT60-style plug: check mate White balance plug: charger only Remove pack for balance charging

MATEK F405-WING V2 - POWER

BAT input: 4S positive + negative
PDB ESC pads: ESC positive + negative 5V peripheral BEC: 2A total
Servo Vx BEC: 5V, 5A continuous

READYTOSKY 40A ESC

Thick DC + / - from FC/PDB
Thin throttle: signal + GND to S1/G BEC red: isolate IF live
Check actual unit despite OPTO title

EMAX ECO II 2807

Three motor phase wires from ESC

Swap any two only if rotation wrong 9045 3-blade prop OFF during setup Current/thrust test before flight

BAT + / - | PDB + / - | 3 wires

### 2 FLIGHT-CONTROLLER SIGNALS + RATED 5V PERIPHERALS

SAME F405-WING V2 - I/O

S1/G : ESC control signal + ground RX2 : receiver servo-iBUS input TX3/RX3 : GPS serial UART3 DA2/CL2 : shared I2C2 bus
TX1/RX1 : SiK air telemetry UART1 S3-S7 : servo PWM outputs
Vx -> Vx2 bridge for S5-S7 power Read actual V2 board pad markings

FLYSKY FS-iA10B RX

servo-iBUS signal -> FC RX2 FC peripheral 5V -> RX +
FC GND -> RX GND; not SENS

RKI-1980 SERIAL AIR RADIO

AIR TX -> FC RX1; AIR RX <- FC TX1 standard GH-6: 1=5V, 2=FC TX1
3=FC RX1, 4/5=CTS/RTS unused 6=GND; verify keyed cable

MATEK M9N-5883 GPS + COMPASS

GPS TX -> FC RX3; GPS RX <- FC TX3 Compass DA -> DA2; CL -> CL2
FC peripheral 5V + GND
Keep compass away from current wires

MATEK ASPD-4525 AIRSPEED

SDA -> DA2; SCL -> CL2 (shared I2C2) JST-GH order: 5V, SCL, SDA, GND
Two silicone pressure tubes -> pitot

iBUS

UART1

GPS + I2C

I2C2

BLACK USB GROUND RADIO

USB -> laptop; radio link to AIR unit

radio / RF link

PITOT AT NOSE

Two tubes to ASPD; prove positive reading

### 2 air tubes

### 3 FIVE MG90S SERVOS - EACH LEAD HAS SIGNAL, +5V AND GND

Use Vx 5V for S3/S4. Bridge Vx to Vx2 for S5/S6/S7 when using the onboard servo BEC.

S3 LEFT AILERON

PWM=S3; Vx 5V; GND

S4 RIGHT AILERON

PWM=S4; Vx 5V; GND

S5 LEFT V-TAIL

PWM=S5; Vx2 5V; GND

S6 RIGHT V-TAIL

PWM=S6; Vx2 5V; GND

S7 NOSE STEERING

PWM=S7; Vx2; GND; gear later

BEFORE POWER: | Propeller off; verify polarity and plug/key order. Isolate ESC BEC red only if live.
BEFORE FLIGHT: | Prove loaded Vx/Vx2, controls/failsafe, pitot, motor current/thrust and CG.
Solid lines = electrical route; purple dashed = radio link; gray dashed = air tubes/optional S7. | Functional connections - check actual keyed contacts

STEP 29

# Power carefully and prove the open installation

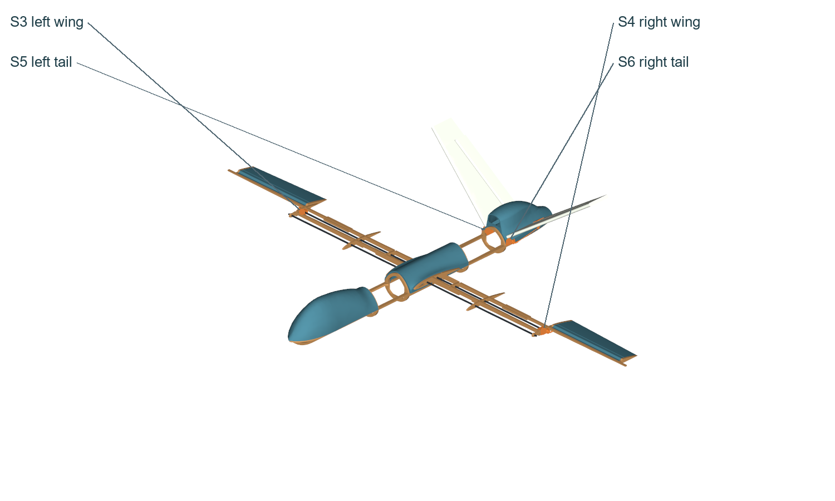
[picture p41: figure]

Orange identifies parts added or checked now. All airframe shapes are placed CAD geometry.
Propeller removed, transmitter on with throttle low: first power the isolated board by USB for inspection. After continuity/polarity checks, test the flight-power wiring with an appropriate current-limited source. Do not exceed any input range.

Measure Vx/Vx2 and peripheral 5 V. Connect accessories one group at a time, watching for heat, wrong polarity and unusual current. Leave servo movement for the following firmware/output checks; then test all four simultaneously on the actual Vx/Vx2 rails under a representative light control load before final skin closure.

Save the observed voltages, load current and any fault. Disconnect battery power before swapping a plug. Correct a mechanical bind before increasing power or adjusting endpoints.

Check nose and cover removal with all harnesses in place. Mark every detachable connector and leave a short service loop without a loose coil near the motor. Take clear photos of the complete open installation for later service.

Check before continuing: Polarity and idle rails pass; no heat or resets; powered servo-load proof stays open until after output configuration.

STEP 30

# Install firmware and save the starting settings

Aircraft orientation reference for checking the ground-station attitude display; software values require readback on the real controller.
With the propeller removed, connect the F405-WING V2 to Mission Planner over USB. In Initial Setup > Install Firmware choose Plane and the exact MatekF405-Wing target supported for the V2 board. Follow the current board instructions; do not flash a similarly named target by appearance.

Connect, record firmware version and board identity, then save a parameter file in Config/Tuning > Full Parameter List before changes. In the attitude display move the airframe by hand: nose down/up and right/left roll must match the display. Set board/compass orientation to the real installation.

Set BRD_ALT_CONFIG=0 for iBUS on RX2 and check channel bars in Initial Setup > Radio Calibration. Turn transmitter V-tail mixing off so the controller owns the mix. Reboot when a parameter instruction requires it, then read the value back.

Menu wording can vary by ground-station version. This procedure is an instruction for your hardware; no aircraft was connected or firmware flashed while creating this guide.

Check before continuing: Correct target/version and baseline file recorded; attitude and every receiver channel respond in the correct sense.

CONFIGURATION

# Assign the actual outputs explicitly

In Full Parameter List set and write the output functions below. Read them back after restart. Output IDs do not establish correct movement; Step 33 proves the directions.

Do not import a ready-to-fly file. Keep S7 steering deferred until measured gear fitting. Start with conservative neutral/endpoints established from free mechanical travel; flight throws require experienced pilot acceptance.

Parameter | Starting value | Actual device
SERVO1_FUNCTION | 70 | Throttle / ESC S1
SERVO3_FUNCTION | 4 | Left aileron S3
SERVO4_FUNCTION | 4 | Right aileron S4
SERVO5_FUNCTION | 79 | Left V-tail S5
SERVO6_FUNCTION | 80 | Right V-tail S6
SERVO7_FUNCTION | 26 later | GroundSteering only after gear fitted
BRD_ALT_CONFIG | 0 | iBUS RX2
SERIAL3_PROTOCOL | 5 if required | GPS on UART3
BATT_VOLT_MULT / BATT_AMP_PERVLT | 11.0 / 66.7 for V2 | Calibrate readings against meter
ARSPD_TYPE / ARSPD_BUS | 1 / 1 for ASPD-4525 | Verify actual firmware bus mapping

Check before continuing: Write, restart as required and read back; final reversal, endpoints and failsafe still need physical tests.

STEP 31

# Calibrate radio, attitude, compass and airspeed

Orange identifies parts added or checked now. All airframe shapes are placed CAD geometry.
Propeller off: follow Radio Calibration and Accelerometer Calibration in Initial Setup. Set known board and compass orientations. Recheck displayed roll/pitch and save changed parameters. Check SiK UART1 and the air/ground pair settings before claiming telemetry works.

Take the aircraft outdoors away from metal and power interference for compass calibration and GPS lock. Check live satellite/position data; keep the compass at its final mounted location. Recheck interference after the power harness is fixed.

Zero ASPD-4525 in still air and inspect both pressure tubes. Use the current ArduPilot airspeed setup for the actual firmware; ARSPD_TUBE_ORDER=2 is auto only if supported. Gently direct airflow toward the pitot and confirm a positive reading. Do not blow strongly into the sensor or assume swapped ports are acceptable.

Compare battery voltage/current with a suitable measured reference. The V2 starting scales are 11.0 and 66.7 A/V, not the older V1 current scale. A displayed sensible number alone is not a calibration.

Check before continuing: Radio endpoints, attitude signs, compass orientation, GNSS and positive airspeed response are recorded; voltage/current agree with measurement.

CONFIGURATION

# Pair the SiK radios and prove telemetry

The AIR unit in the frame sends telemetry; the GROUND USB unit remains at the computer. Teal lines show actual-frame harness routes.
Fit the correct antennas to both radios before powering them. With the ground station disconnected from the vehicle, choose the GROUND USB radio COM port at 57600 baud. In Mission Planner open Initial Setup > Optional Hardware > SiK Radio and Load Settings for local and remote units.

Inspect the pair before changing good defaults. Net ID and required Air Speed/ECC settings must agree. If they do not, use Copy Required Items to Remote and Save Settings per the current SiK procedure. AIR serial baud must match FC UART1; GROUND serial baud must match the computer. Do not invent radio transmit power or range.

On the F405 set SERIAL1_PROTOCOL=1 for MAVLink1, or 2 only if the radio firmware supports MAVLink2; SERIAL1_BAUD=57 means 57600. Write, restart as required and read back the values. These settings apply to TX1/RX1, not the GPS UART.

A solid green SiK link LED indicates a paired link; blinking indicates searching. Select the GROUND COM at its matching baud and Connect. Check live heartbeat/parameters and tilt the aircraft to see Flight Data attitude update over radio. If it fails, disconnect flight power before checking crossed TX/RX, supply/ground, baud and pair settings. Keep USB available for recovery.

Check before continuing: Actual radio-link connection and live attitude/parameters pass; a lit power LED alone does not prove telemetry.

STEP 32

# Check motor direction without a propeller

Orange identifies parts added or checked now. All airframe shapes are placed CAD geometry.
Secure the airframe, clear the motor bell and keep the propeller removed. Follow the actual ESC calibration procedure if its protocol requires it; do not run a generic calibration blindly.

Command only a short low-power direction test with a means to disconnect power. Confirm the rear pusher rotates in the intended direction for the actual prop. If wrong, disconnect battery and swap any two motor phase leads; repeat the test.

Stop for vibration, rubbing, heat or loose mount contact. Check every motor screw and the frame joint afterward. This unloaded motor test does not qualify the 9045 three-blade prop on 4S.

Check before continuing: Rotation agrees with the actual pusher prop orientation; motor runs smoothly and the mount stays secure.

STEP 33

# Prove every control direction and failsafe

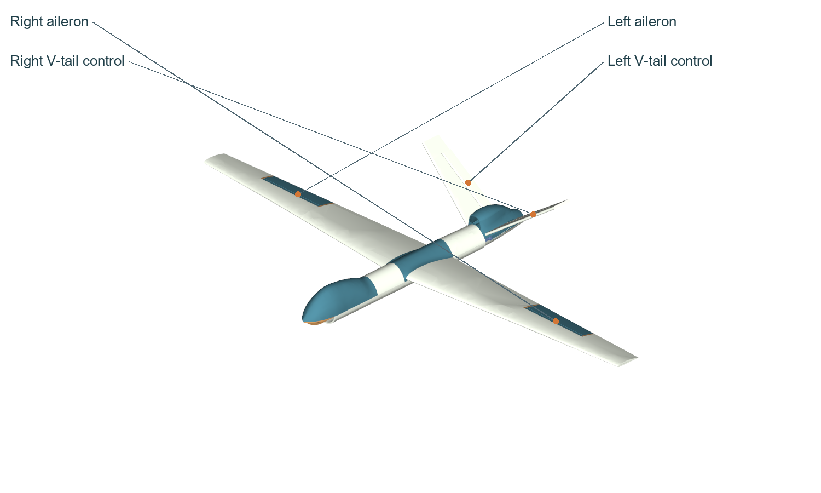
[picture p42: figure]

Orange identifies parts added or checked now. All airframe shapes are placed CAD geometry.
In manual mode command roll right: right aileron trailing edge rises, left lowers; roll left reverses both. On this upright V-tail, pitch up raises both trailing edges, pitch down lowers both. Viewed from behind toward the nose, yaw right shifts both trailing edges toward aircraft right; yaw left shifts both toward aircraft left. Test pitch/yaw together and have an experienced builder verify the mix.

In stabilized mode raise the nose: both tail trailing edges must lower; lower the nose: both rise. Roll the right wing down: right aileron must lower and left rise to oppose the disturbance. If wrong, check board orientation, function assignment and the specific output reverse. Change one cause, then repeat every direction and mode.

At all combined endpoints check no bind, horn peel, pin escape, cable snag or servo stall. Record neutral, physical throws and endpoints. Reducing software travel must not hide a broken mount.

Propeller off, test transmitter loss in a controlled setting. Verify the intended safe throttle and mode action and its recovery on the actual receiver/controller, then perform the radio manufacturer range check. Repeat these tests after firmware, output, reversal or linkage changes.

Check before continuing: Manual and stabilized responses are correct in all directions; failsafe/recovery and free combined travel pass and are logged.

STEP 34

# Fit lower body wraps after open checks

Orange identifies parts added or checked now. All airframe shapes are placed CAD geometry.

First bond the previously dry-fitted wing skins after powered direction, failsafe and loaded Vx/Vx2 checks have passed. Use qualified foam adhesive progressively with each wing supported straight, retain servo service access, keep hinges clear and support through full cure. Repeat travel and symmetry checks.

FW07 is the long lower body wrap replacing A56/A17 surface faces. FW08 covers the aft lower body A42. FW11 is the tail underside A20. Use the already-cut outlines; the FW07 205 mm cross-line is a hand station reference.

Precurve progressively, peeling inner paper where the documented wrap requires it while preserving outer paper. Trial FW11 in paper first; its compound curve may need short overlapping perimeter darts while remaining one connected piece. Do not flatten a buckle by crushing the core.

Keep the later gear openings and battery restraint path open. Confirm motor screw access, tail adjusters and wire routing once more, then bond fixed lower-wrap contacts progressively with the qualified foam adhesive. Hold shape through full cure and tape fixed seams.

Check before continuing: Lower wraps follow the frame, no wires are trapped, later gear access remains open and the nose remains removable.

STEP 35

# Fit removable top covers and centre fairing

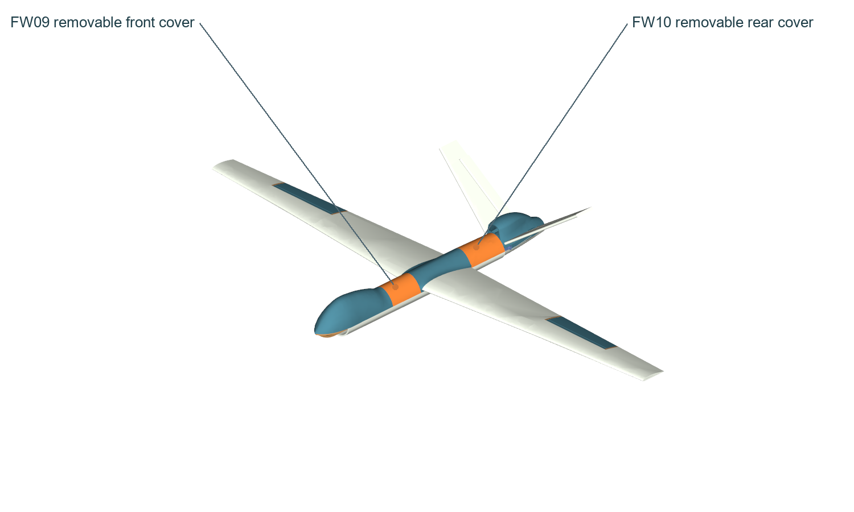
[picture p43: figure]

Orange identifies parts added or checked now. All airframe shapes are placed CAD geometry.
FW09 is the front upper body A08 and FW10 the aft upper body A15. Trial over the fully wired aircraft alongside A06 centre fairing, A59 nose and A12 tail carrier. Make only local dry-fit relief; do not recut a whole sheet.

Retain front/rear access covers with removable tape/ties at fixed skin/frame contact. Keep release edges reachable. Do not permanently glue closed the battery, FC USB/SD, wing connectors, tail linkage or motor service path.

Open and close each cover with the pack disconnected; remove and reinstall the battery without pulling a sensor hose or harness. Tape exposed fixed paper edges but keep all hinges free. Take the final access photos.

Check before continuing: Every required service point is reachable after closing; the pack is independently restrained and can be removed safely.

STEP 36

# Park safely until gear work after midsems

Orange identifies parts added or checked now. All airframe shapes are placed CAD geometry.
Landing gear fitting is deferred. Leave S7 and its steering linkage inactive, keep gear openings and A25/A47/A48 structure inspectable, and support the aircraft on padded cradles away from control surfaces.

After midsems measure the purchased gear, axle height, mounting footprint, steering clearances and supplied fasteners. Spread its landing loads into the wood skeleton; foam is not the landing-load mount. The original gear prints are not an automatic substitute.

Fit MG90S S7 only after its actual gear linkage is established. Set SERVO7_FUNCTION=26 and appropriate GROUND_STEER_ALT per the current manual, then test direction and travel without binding. Obtain physical mount/load acceptance before taxiing.

Check before continuing: Deferred gear work is clearly identified; no taxi or flight is attempted with an unqualified attachment.

PHYSICAL ACCEPTANCE

# Physical acceptance gate 1: structure and balance

Inspect the internal load paths shown before and after each physical test; reopen service covers if needed.
Record the completed mass with the flight pack, straps, propeller/hub, final gear, wiring and fasteners. Measure lateral balance and fore/aft CG physically. The old Y74 / 20%-chord value is a geometric starting point, not an approved stability range.

Choose any provisional balance target with an experienced aircraft builder from the actual final geometry and mass distribution. Moving the battery must preserve real frame support, restraint and removal access. A predicted balance point cannot approve a position that clashes with A34.

Agree progressive representative load tests for the keel and spar laps, roots/rods, reinforced plywood A44 servo supports, tail carrier, horns, motor mount and gear load path. Support the aircraft safely and record applied loads, deflection and recovery. Stop for cracks, slip, permanent bending or adhesive peel.

These drawings and mesh checks establish digital geometry only. No structural capacity, fatigue life or safe flight load is certified. Continue to powered propulsion testing only after the actual structure, restraint and controls are accepted.

Check before continuing: Gate stays closed until mass/CG, joint and control-load evidence are recorded and reviewed.

PHYSICAL ACCEPTANCE

# Physical acceptance gate 2: propulsion and ground

No flight-ready claim is made. The pictured aircraft remains an intended assembly until real acceptance is completed.
Qualify the exact EMAX ECO II 2807 1300KV, owned 9045 three-blade prop, 4S pack and ReadytoSky 40A ESC as one combination. The manufacturer recommends 6-7 inch propellers; a 9-inch prop requires actual current, thrust and temperature testing.

Use a secure purpose-made test restraint and competent help. Clear the complete propeller plane, fit the verified pusher prop/hub correctly and provide a safe disconnect. Record battery voltage sag, current, thrust, motor/ESC temperatures, vibration and mount movement progressively. Stop if the hardware limits are exceeded or any part loosens.

After qualified gear fitting, load the aircraft to its completed mass. Check propeller-ground clearance with gear deflection and nose-raised rotation, using the entire 228.6 mm prop disk. Inspect steering, tracking, braking/rolling behavior and attachment after controlled ground tests.

Thrust, launch method, runway requirement, endurance and safe control throws remain unestablished until tested and reviewed. Obtain experienced pilot acceptance of structure, CG, propulsion, controls, failsafe and site before any flight attempt.

Check before continuing: Flight remains gated until all physical evidence and pilot acceptance are documented. Passing a CAD or bench check alone does not open this gate.

REFERENCE

# If a check fails

Symptom | Stop and inspect | Safe next action
Wood tab will not seat | Orientation; measured thickness; documented relief | Compare actual mates; pare only specified local patches
Motor holes miss | Exact motor label; diameter19 PCD; actual mount | Template against real base; measure before any drilling
Servo buzz or binds | Horn/arm travel; pushrod rub; pin retention | Power off; fix mechanical cause; retest all directions
Board resets on servo motion | Vx/Vx2 voltage, BEC load and short | Prop off; isolate loads; correct supply/connection
Airspeed is negative/unstable | Ports, tube kink/leak, zero, exact sensor SKU | Identify actual ports/manual; test gentle positive flow
GPS/compass disturbed | Power wiring/metal distance; orientation | Reposition with measured clearance; recalibrate
Battery cannot be removed | Straps; nose/cover; hose and plug routing | Disconnect; revise service route before closing
Print/wood bond peels | Surface preparation, compatibility, cure | Remove load; remake tested joint; inspect all similar joints

Check before continuing: Record the failure and correction. Repeat every affected earlier check; do not continue because the cover hides it.

REFERENCE

# Foam ID to installed shape

Cut pattern | Installed CAD ID / plain name | Blank count
FW01 / FW02 | A52 left / A49 right inner wing | Whole: 2; split ROOT/TIP: 4
FW03 / FW04 | A38 right / A27 left outer wing | 2
FW05 / FW06 | A57 right / A22 left fixed V-tail | 2
FW07 | A56 + A17 forward/middle lower body | 1
FW08 | A42 aft lower body | 1
FW09 / FW10 | A08 forward / A15 aft upper covers | 2
FW11 | A20 tail underside | 1
FW12 / FW13 | A41 right / A60 left moving tail | 2 per side, laminate to 10 mm

Check before continuing: Existing whole skins need no new seam. Already split skins need only their documented straight ROOT/TIP joins.

REFERENCE

# Print the missed aircraft pieces

Reuse sound prints and reprint missed or rejected parts. A11_2W_10GYR_SUP_L0p2_B8.stl is the left aileron; A21_2W_10GYR_SUP_L0p2_B8.stl is the right. Their upright orientation requires actual printer-height confirmation. A23 is the left fixed hinge rail, A36 the right. HTRB is the right tail-horn backing plate. These supplied STL geometries are unchanged.

A23/A36 filenames carry 3W_15GYR_NOSUP_L0p2_B8; each upright file is 16.676 x 19.699 x 270.204 mm. Confirm usable printer height, including any adhesion layers. HTRB_3W_100RECT_NOSUP_L0p2_B5.stl lies broad face down and is 22 x 24 x 1.5 mm.

Source settings recommend PLA+; the currently available spool is PLA. Use the actual filament-maker temperature range and a calibrated profile at 100% millimetre scale. PLA and PLA+ are not interchangeable strength ratings; qualify layer bonding, hinge/pin fit and cured joints on the actual prints.

Use 0.4 mm nozzle, 0.20 mm layers and initial 4 top/4 bottom solid layers. Inspect thin edges, supports, bores and complete skins in the slicer, print a fit coupon and reject cracked or warped parts. The plywood A44 ribs and A26 firewall are not printed in this cutting set.

IDs | Walls / infill | Supports / brim
A06 / A11 / A21 | 2 / 10% gyroid | Build plate only / 8 mm
A12 | 2 / 15% gyroid | Build plate only / 8 mm
A23 / A36 | 3 / 15% gyroid | Off / 8 mm
A45 / A55 | 4 / 35% gyroid | Off / 8 mm
HWL / HWR / HTLB / HTRB | 3 / 100% rectilinear | Off / 5 mm
HTL / HTR | 3 / 100% rectilinear | Build plate only / 5 mm

REFERENCE

# Record acceptance and keep the sources

Keep one build record: actual stock thickness, print masses, adhesive product/cure times, measured pin and servo-tab fits, motor pattern/thread engagement, voltage/current calibration, control throws, failsafe, structural loads, propulsion results, final mass/CG and pilot review.

Geometry and part identity come from the supplied source assembled CAD and R5 placed assembly, wood/print/foam records and removal solids. The original construction source is Michael Rechtin, Building a DIY REAPER Drone... Ended Badly. The current plywood ribs, rear mount and keel must remain paired with their current cutting set and local finishing details.

After every hard landing, ground strike or failed test inspect the high-load joints inside the access covers. Log the correction and repeat affected tests before an experienced pilot accepts the aircraft again.

Matek F405-WING V2 board and power (https://www.mateksys.com/?portfolio=f405-wing-v2)

Matek M9N-5883 GPS / compass (https://www.mateksys.com/?portfolio=m9n-5883)

Matek ASPD-4525 airspeed sensor (https://www.mateksys.com/?portfolio=aspd-4525)

FlySky FS-iA10B receiver (https://www.flysky-cn.com/ia10b-canshu)

ArduPilot Matek board and configuration (https://ardupilot.org/plane/docs/common-matekf405-wing.html)

ArduPilot output functions (https://ardupilot.org/plane/docs/servo-functions.html)

ArduPilot V-tail direction checks (https://ardupilot.org/plane/docs/guide-vtail-plane.html)

ArduPilot airspeed setup (https://ardupilot.org/plane/docs/airspeed-parameters-setup.html)

ArduPilot Plane failsafe (https://ardupilot.org/plane/docs/apms-failsafe-function.html)

ArduPilot UART telemetry settings (https://ardupilot.org/plane/docs/common-telemetry-port-setup.html)

EMAX ECO II 2807 official motor (https://shop.emaxmodel.com/products/emax-eco-ii-series-2807-1300kv-1700kv-1500kv-brushless-motor-for-rc-drone-fpv-racing)

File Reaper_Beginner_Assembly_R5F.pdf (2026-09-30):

START

# Reaper: build one stage at a time

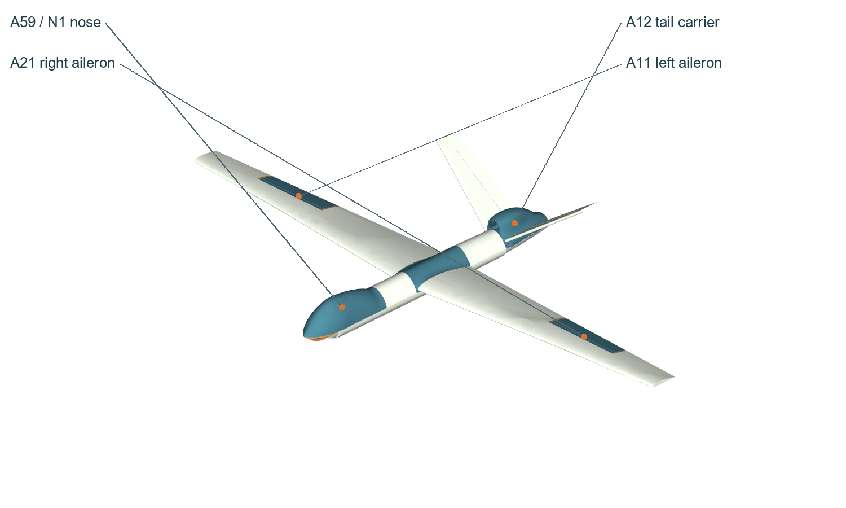
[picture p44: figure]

Intended upright V-tail aircraft from actual assembly CAD. Landing gear and propeller are deliberately absent at this build stage.
DARTS founding project - registration pending. This separate follow-along guide takes your existing cut parts and prints through assembly, wiring and bench checks. Landing gear is a later stage after midsems.

Reuse the foamboard, plywood and sound prints you already have. Read the next step before bonding; if that stage is already built, perform its check and continue. A44_L and A44_R are now printed outer ribs; A26 is a printed replacement motor firewall. A11 and A21 are the unchanged ailerons that were missed in printing.

Keep the propeller off throughout assembly, wiring and configuration. Physical fit, cured joints, control operation and propulsion must be proved on your aircraft. Passing the drawings or bench checks does not make it flight ready.

Abhinav Pullela . mcarkade | Contents | 1

START

# Contents

Reaper: build one stage at a time | 1
Start with the parts you have | 3
Tools, glue and curing | 4
01. Finish the known wood seating errors | 5
02. Align the two keel halves | 6
03. Bond both keel side laps | 7
04. Dry-fit the horizontal body frames | 8
05. Add the two forward body formers | 9
06. Add the two aft body formers | 10
07. Fit the gear-bay pieces and tail bulkhead | 11
08. Trial the printed body parts, then bond the wood | 12
09. Align each rear wing spar | 13
10. Bond both face laps on each spar | 14
11. Build the right wing with its printed outer rib | 15
12. Build the left wing and compare both sides | 16
13. Fit both roots and the two whole carbon rods | 17
14. Install the fixed aileron rails and endplates | 18
15. Fit the unchanged ailerons and captive pins | 19
16. Mount wing servos, horns and pushrods | 20
17. Form and fit the fixed upright V-tail | 21
18. Laminate the moving tail controls and hinge them | 22
19. Fit the two tail servos and backed horns | 23
20. Check the complete open structure | 24
21. Form the inner wing skins you already cut | 25
22. Dry-fit outer skins and keep access open | 26
23. Place and restrain the battery and electronics | 27
24. Place GPS, pitot and airspeed tubes | 28
25. Resolve and trial the rear motor interface | 29
Motor fitting detail: keep the rest of the frame | 30
26. Connect high-current power with the prop off | 31
Power and motor connection map | 32
27. Connect servo power and receiver | 33
28. Connect sensors and the SiK air radio | 34
Receiver, sensor and radio map | 35
Complete wiring foldout | 36
29. Power carefully and prove the open installation | 37
30. Install firmware and save the starting settings | 38
Assign the actual outputs explicitly | 39
31. Calibrate radio, attitude, compass and airspeed | 40
Pair the SiK radios and prove telemetry | 41
32. Check motor direction without a propeller | 42
33. Prove every control direction and failsafe | 43
34. Fit lower body wraps after open checks | 44
35. Fit removable top covers and centre fairing | 45
36. Park safely until gear work after midsems | 46
Physical acceptance gate 1: structure and balance | 47
Physical acceptance gate 2: propulsion and ground | 48
If a check fails | 49
Fuselage wood | 50
Fuselage wood continued | 51
Wing wood | 52
Wing wood continued | 53
Wing wood continued | 54
Printed aircraft parts | 55
Printed aircraft parts continued | 56
Printed aircraft parts continued | 57
Foam installed shapes | 58
Foam installed shapes continued | 59
Foam ID to installed shape | 60
Print the missed pieces and the current ribs | 61
Record acceptance and keep the sources | 62

START

# Start with the parts you have

Right and left mean the pilot looking toward the nose. The nose is the narrow front end; the motor is at the rear. In drawings, X runs across the wings, Y increases aft and Z is upward. All quoted dimensions are millimetres unless stated otherwise.

The source wing span is 2.00 m. Two whole 5 x 1000 mm carbon rods support the wings across the centre. Plywood is nominal 6 mm and foamboard nominal 5 mm; measure your stock. Never scale parts to solve a fit.

Sort pieces into fuselage, right wing, left wing, tail and electronics bags. Match IDs to the part pictures in this guide. A40 is already incorporated into the unified A62 keel; do not stack another A40. Keep old wooden A44 ribs aside as references; fit the printed pair instead.

FW01/FW02 inner foam skins may be whole R5C cuts or R5E ROOT/TIP pairs. Both use the same final outline. Keep whole skins intact; join only skins already supplied as two pieces. Existing R5C plywood needs the documented local fitting in the next pages, not a full new cutting job.

START

# Tools, glue and curing

Use a flat board, straightedge, square, calipers, sharp knife, sanding block, clamps, hand drill, smooth trial pin, reinforced tape, zip ties, Velcro straps, soldering iron, heat-shrink and multimeter. For early servo centring use a regulated 5 V supply and standalone servo tester with neutral mode; availability is unconfirmed. A current-limited source helps the first electrical check.

For close wood-to-wood joints, use a wood adhesive approved for the plywood and clamp full contact. For print-to-wood joints, lightly abrade only the bond patch, remove dust, and qualify an adhesive explicitly compatible with both the chosen filament and wood. A gap-filling two-part epoxy is a candidate only after its offcut test passes.

For foam use an adhesive explicitly approved for its foam core and paper. Ordinary CA and solvent glue can damage exposed foam; test the exact product first. Hot glue can locate light equipment but must not be the sole battery restraint or proof of a loaded joint.

Write the exact adhesive name, mix ratio if required, working time, clamp time and full-cure time from its label on a bench card. Apply at the stated temperature. Keep each joint supported for the label clamp time and unloaded until full cure. No exact adhesive is identified in the local BOM, so there is no universal hour value to copy.

Bond one wood lap, one print-to-wood offcut and one foam fold first. After full cure pull and bend the samples. Stop if paper peels, plastic separates, the core melts or the bond remains soft; choose and test a compatible adhesive before using it on the aircraft.

Check before continuing: Continue only when the exact adhesives, clamp times and full-cure times are written down and the sample joints pass.

STEP 01

# Finish the known wood seating errors

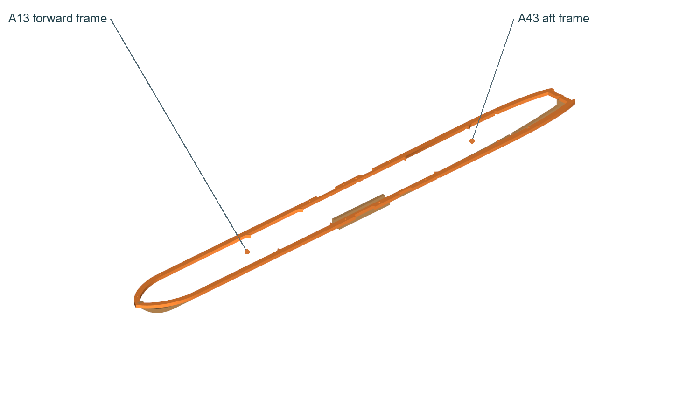
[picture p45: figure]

Lower detail: orange volumes are material to remove from A43 at the gear-bay seats. They are not extra aircraft pieces.

Dry-fit the complete cut pieces before glue. The R5C cut DXFs describe stock blanks; the finished CAD includes local paring. These are documented corrections to already-cut wood.

On A43, the two gear-bay seats at Y125-131 and Y142.7-148.7 lose 1 mm from the underside locally, leaving 5 mm. The seats against A16 and A04 also require local relief to the removal shape. Keep the surrounding A43 at 6 mm.

A05_L/R and A07_L_I/R_I need local relief at inner/middle rib tabs, around X53-59 and X247.35-253.35 and their mirrors. A62_F needs local relief at A54, Y-5 to 1. Use the actual mating part and source removal detail as the stop; a whole bounding rectangle is not a removal instruction.

Dress the tiny A53 and outer rear-spar edge wedges only if they prevent seating. Make small cuts, refit and stop when each joint seats without force. If a defect lies outside these locations, mark it and measure it before removing structural material.

Check before continuing: Slots seat fully without bending parts; no entire former, spar or endplate has been thinned.

STEP 02

# Align the two keel halves

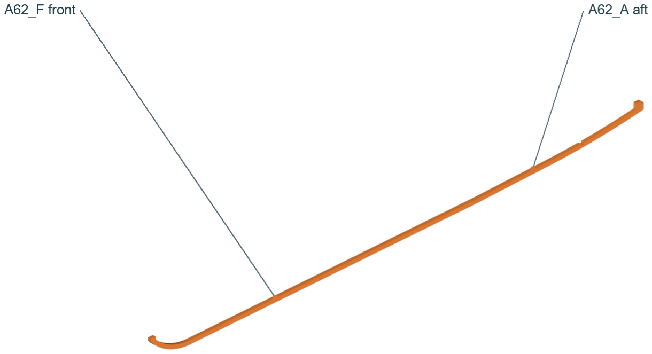
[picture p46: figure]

Orange identifies parts added or checked now. All airframe shapes are placed CAD geometry.
Take A62_F (front keel) and A62_A (aft keel). Stand their broad side faces in one plane on a straight jig, matching the top and bottom edge shapes. The butt seam is at Y100.

Use the A13/A43 frames loosely as an alignment check before bonding. Do not use glue to fill a misaligned step. The seam locates the halves; the two side laps in the next step carry the joint.

Check before continuing: A straightedge crosses the seam without a step or kink, and the dry frames seat.

STEP 03

# Bond both keel side laps

Orange identifies parts added or checked now. All airframe shapes are placed CAD geometry.
Fit A62_DL to the left broad side and A62_DR to the right side of the aligned keel. Each 120 mm lap spans Y40-160, giving 60 mm on each half. Align their lower edges with the keel at Z-41.714.

Apply the qualified wood adhesive to the complete mating faces. Clamp the halves and both laps flat in the jig. Wipe squeeze-out away from nearby slots. Keep the jig in place through clamp time and leave the joint unloaded through full cure.

If the keel is already joined, inspect both laps, the straight seam and the cured contact. Do not dismantle a sound joint to repeat this step.

Check before continuing: Both opposite laps are installed, fully bonded and straight; no loose edge, soft glue or split wood.

STEP 04

# Dry-fit the horizontal body frames

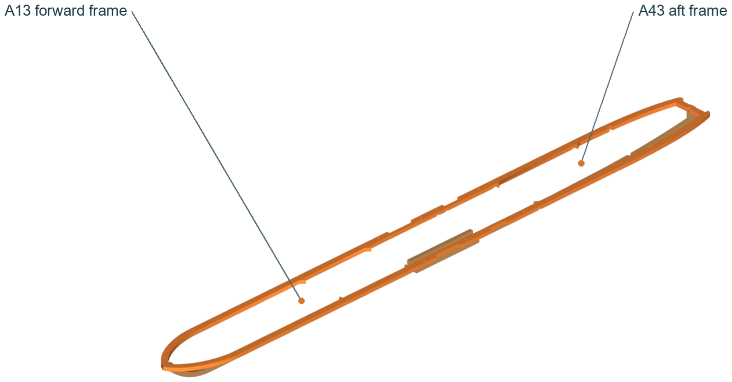
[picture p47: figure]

Orange identifies parts added or checked now. All airframe shapes are placed CAD geometry.
Fit A13 at the front and A43 at the rear onto the keel tabs. Their upper faces are the common Z0 plane. The rounded front of A13 points toward the nose; A43 runs toward the motor.

Keep the assembly supported so the thin frame members do not bow. Fit without glue now; the formers, gear-bay pieces, nose and tail carrier must all agree before you bond the body.

Check before continuing: The frames sit level on a straight keel, all tabs seat and the structure stays
square without force.

STEP 05

# Add the two forward body formers

Orange identifies parts added or checked now. All airframe shapes are placed CAD geometry.
A34 is the front ring former, with its forward face at Y-130. Fit its lower slot and frame contacts first. A54 is the centre ring former, with its forward face at Y-5: 125 mm aft of A34.

The former rings stand upright across the body. Keep their top arcs above the frame and their lower notches toward the keel. Check a square against each ring. Use the local A62_F relief from Step 1 if A54 will not seat.

Check before continuing: The two rings are upright, square to the centreline and 125 mm apart between forward faces.

STEP 06

# Add the two aft body formers

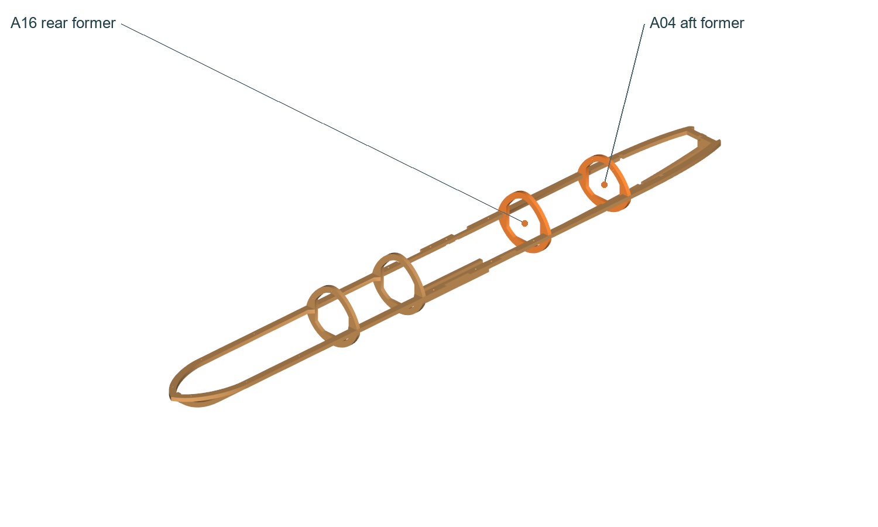
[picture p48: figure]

Orange identifies parts added or checked now. All airframe shapes are placed CAD geometry.
Fit A16 with its forward face at Y233.65, then A04 with its forward face at Y384.65. From the A34 forward face these distances are 363.65 and 514.65.

Keep each ring square and the top of A43 at Z0. If a former lifts A43, use only the documented local underside seat relief. Trial a lower foam wrap over the rings to see whether the body outline remains smooth.

Check before continuing: All four ring formers seat without twisting the body; left and right frame rails remain level.

STEP 07

# Fit the gear-bay pieces and tail bulkhead

Orange identifies parts added or checked now. All airframe shapes are placed CAD geometry.
Dry-fit A25 at Y125 and A48 at Y142.7, then A47 across their matching tabs. These three pieces stay in the wood skeleton even though purchased landing gear is deferred until after midsems.

Fit A18 tail-carrier bulkhead with its aft face at Y460.5. Its raised centre and opening locate the printed A12 carrier. Preserve the surrounding slots and motor-driver approach.

Leave the motor mount out until its separate fit step. Existing gear-bay structure is not proof of a bolt pattern or load capacity for the later gear.

Check before continuing: A25/A47/A48 sit flat and A18 is square; later gear and motor access remain open.

STEP 08

# Trial the printed body parts, then bond the wood

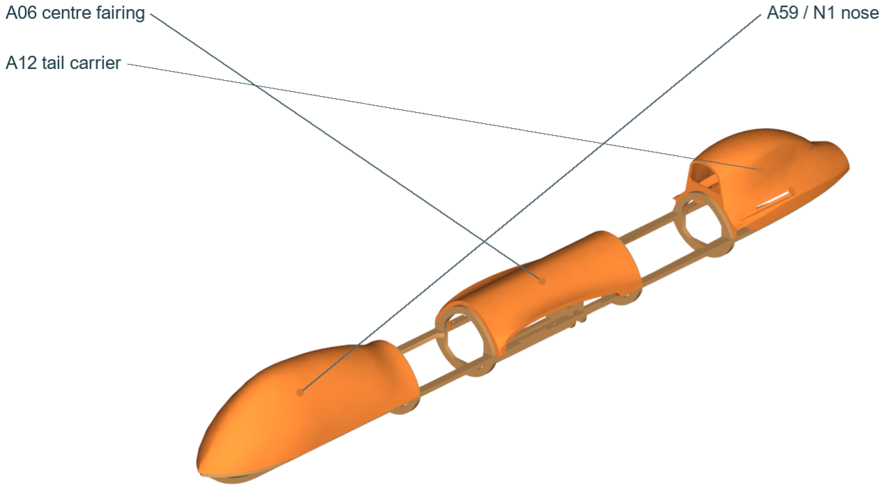
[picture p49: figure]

Orange identifies parts added or checked now. All airframe shapes are placed CAD geometry.
Slide the owned A59/N1 nose over the forward frame, place A06 centre fairing over the centre body and seat A12 tail carrier against A18. Put the parts on and take them off before applying adhesive. Do not force a shell over proud wood tabs.

The prints attach at their actual wood seating faces and sockets. A12 surrounds the tail bulkhead; A06 follows the centre formers and frame; A45/A55 roots seat against the wing structure and locate the two carbon rods. These contact patches carry load into the skeleton. Foam skin and tape can close seams but cannot replace the sound wood-to-print joints.

Mark which print contacts need the qualified print-to-wood adhesive. For the nose and access covers retain a removable path using tape/ties at sound frame contact, rather than sealing electronics inside. There is no dimensioned universal screw pattern for all shells.

When the complete dry body aligns, remove shells, bond wood contacts and clamp square through label clamp time and full cure. Then bond A12 to its A18 seating faces with the qualified print-to-wood adhesive and hold square until fully cured. Retain A06 serviceably with tape/ties at sound frame contact. Keep the nose removable, the motor mount out and the body open.

Check before continuing: The cured wood is straight; shells seat by hand and motor, battery and USB/SD access can be reached.

STEP 09

# Align each rear wing spar

Orange identifies parts added or checked now. All airframe shapes are placed CAD geometry.
On the right, align A07_R_I (inner section) with A07_R_O (outer section). Their seam is at X360. On the left use A07_L_I and A07_L_O, with the mirrored seam at X-360.

Lay each spar broad face on a flat jig. Keep its notches facing the matching ribs. Trial-fit the ribs before glue so a reversed half is caught now.

Check before continuing: Each spar is straight across its seam and its notches match the correct-side ribs.

STEP 10

# Bond both face laps on each spar

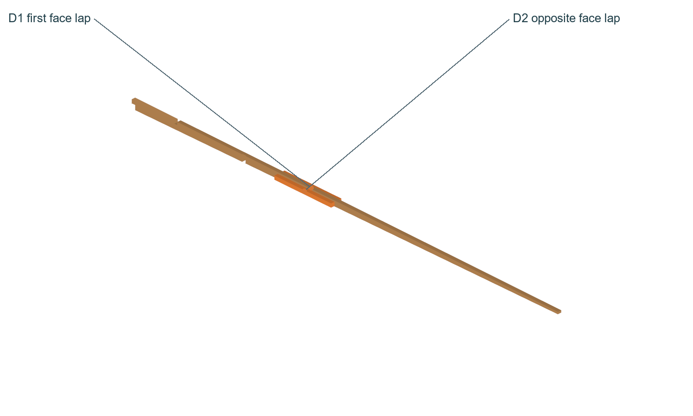
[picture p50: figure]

Orange identifies parts added or checked now. All airframe shapes are placed CAD geometry.
Fit A07_R_D1 and A07_R_D2 to opposite broad faces of the right spar. Each 100 mm lap covers X310-410, giving 50 mm per half. Repeat with A07_L_D1/D2 on the left.

Bond full contact with the qualified wood adhesive. Clamp straight and keep glue out of rib notches. Both laps are structural pieces; a rigid-looking butt joint is not a reason to omit one. Leave unloaded until full cure.

Check before continuing: Both spars have two opposite cured laps, straight edges and open rib seats.

STEP 11

# Build the right wing with its printed outer rib

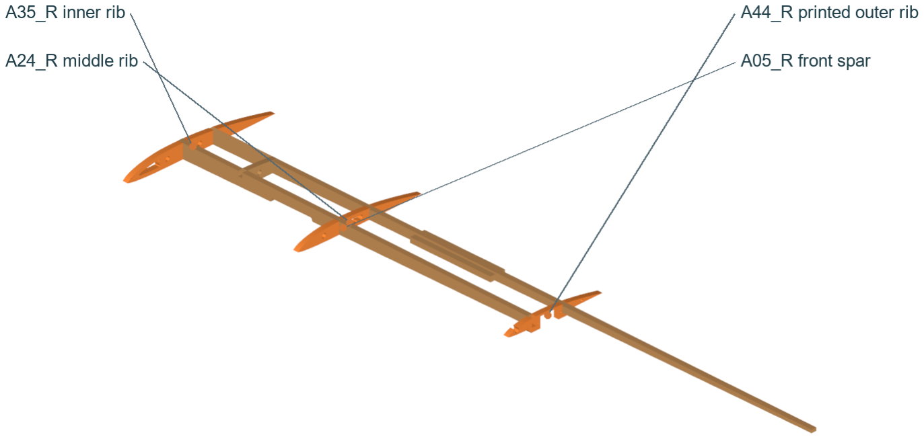
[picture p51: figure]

Orange identifies parts added or checked now. All airframe shapes are placed CAD geometry.
Lay out A05_R front spar, the joined A07_R rear spar, A35_R inner rib, A24_R middle rib and A01_R rear-rod support rib. Fit the printed A44_R outer rib instead of its cut wooden predecessor.

The ribs run fore-aft with their rounded noses toward the leading edge. Inner rib datum is about X53, middle about X250 and outer about X490. The front and rear spars run spanwise through their matching seats. A01_R supports the rear rod near X130.

Dry-fit first, including the real servo in A44_R and the outer skin. Keep the airfoil shape, spar seats and servo opening intact. Bond wood-to-wood seats using the tested wood adhesive; use the tested print-to-wood adhesive only at A44_R mating patches. Support the assembly without twist through full cure.

Check before continuing: Every rib seats, the printed outer rib preserves the source airfoil and real servo access is clear.

STEP 12

# Build the left wing and compare both sides

Orange identifies parts added or checked now. All airframe shapes are placed CAD geometry.
Repeat Step 11 with A05_L, A07_L, A35_L, A24_L, A01_L and printed A44_L. This is a mirror, not a second right wing. Keep the servo pockets and control attachments on their correct sides.

Compare both frames on the same flat board before adhesive cures: rib stations, leading edges, spar joints, root faces and twist. Trial each outer foam skin and fixed hinge rail. Correct only a proven local interference, never shorten one wing to match a mistaken fit.

Check before continuing: Left and right rib spacing, airfoil attitude and root-to-tip straightness match.

STEP 13

# Fit both roots and the two whole carbon rods

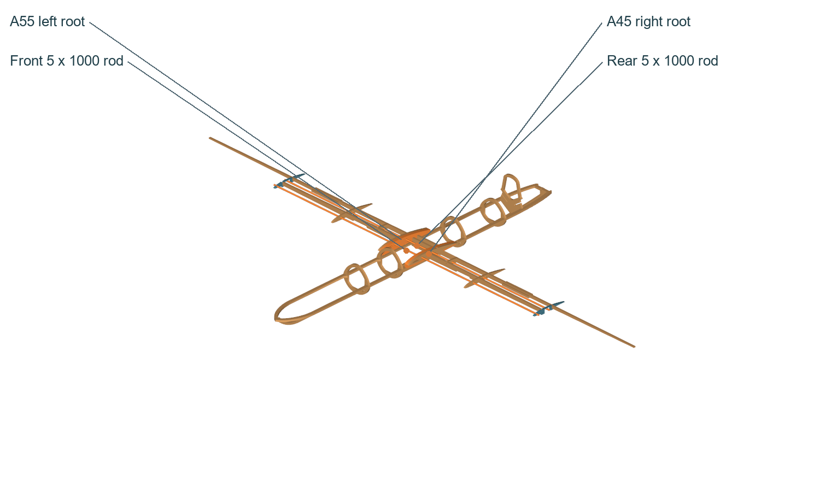
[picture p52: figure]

Orange identifies parts added or checked now. All airframe shapes are placed CAD geometry.
Fit A55 left root and A45 right root with the complete body and both wing frames supported. Slide the front rod through the nominal 5.2 mm printed bores and mating wood seats at Y60.454/Z15.632. Slide the rear rod at Y100.500/Z15.070.

Each rod is solid carbon, 5 mm diameter and 1000 mm long, centred from X-500 to +500. Keep both whole; do not cut or butt-join them at the body. The outer front-rod seat is an open local notch.

Trial the actual rods, roots and wood simultaneously. Finish a bore locally only enough for a snug fit; do not scale a root. Mark the loaded root-to-wood contact and bond only after a qualified offcut joint and full dry fit.

Before covering, prove that neither a wing nor a rod can move out spanwise. The source does not define a fully qualified removable locking system. A friction fit alone is insufficient: hold this stage for a documented positive restraint and physical pull/load check if the installed bonded arrangement cannot resist escape.

Check before continuing: Rods remain whole; both roots seat without cracks; wings and rods have demonstrated restraint against escape.

STEP 14

# Install the fixed aileron rails and endplates

Orange identifies parts added or checked now. All airframe shapes are placed CAD geometry.
Right side: fit A36 fixed hinge rail with A53_R inner wooden endplate and A10_R outer endplate. Left side: A23 with A53_L and A10_L. Trial the corresponding moving aileron before bonding the fixed pieces.

The endplates lie beyond the moving surface ends, not inside its free span. Preserve their pivot-support material. The inner A53 datum remains about X493 on the right and its mirror on the left. Keep the printed rail aligned with the common hinge line.

Use qualified wood adhesive at wood contacts and qualified print-to-wood adhesive at the fixed rail contact. Keep all hinge pilots free of glue and leave space for the captive pin heads.

Check before continuing: Both rails are fixed and straight; moving ailerons can fit between their endplates without being pinched.

STEP 15

# Fit the unchanged ailerons and captive pins

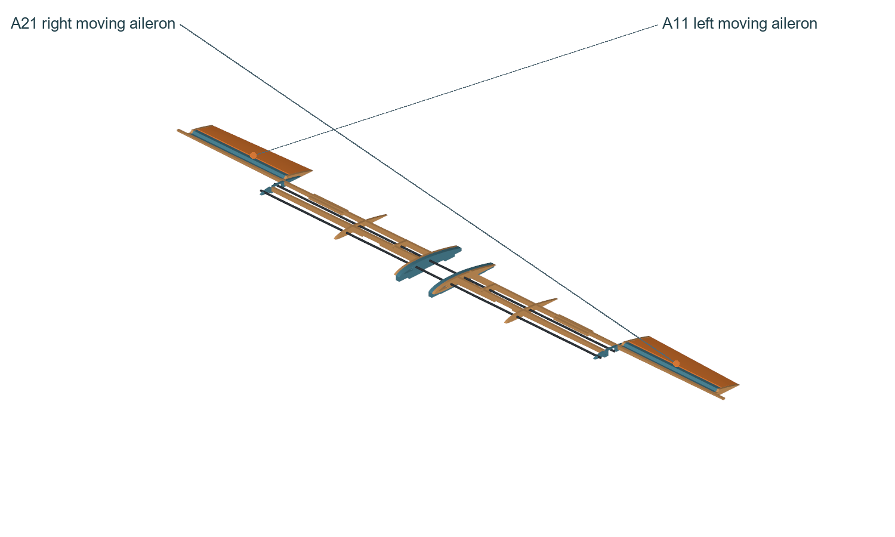
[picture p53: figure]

Orange identifies parts added or checked now. All airframe shapes are placed CAD geometry.

Use A21 on the right and A11 on the left. These are the existing unmodified print geometries supplied again because they were missed. Use their 2 mm common-axis pilots, not a full-length hinge shaft.

Measure the actual spoke/pin diameter. Align the two end pilots and finish them carefully to a smooth rotating fit. Each aileron uses two short end pins. Keep adhesive out of the bearing and keep the surface clear of its fixed rail.

Make bent L heads from suitable spoke offcuts, and trap each head against the wooden endplate with reinforced tape or a tie. The head must remain clear of the moving surface and cannot slide out. Test the restraint in both directions; replace tape if it peels or allows pin movement.

Check before continuing: Both ailerons move freely; four end pins are positively captive without bearing glue or hinge rub.

STEP 16

# Mount wing servos, horns and pushrods

Actual airframe, horns and source servo envelopes. Arm and pushrod cylinders illustrate a route; set length and captive bends on the real parts.

Fit an MG90S at each printed outer-rib pocket: S3 left and S4 right. Before fitting arms, keep flight battery/ESC disconnected and prop removed. Connect one servo to a standalone tester: verified signal to signal, positive to regulated 5 V and ground to ground, following its keyed contact view. Select neutral mode; then fit the factory arm near a right angle to the pushrod and retain its supplied centre screw.

If no verified 5 V tester is available, leave arms off and skins open. Complete the bench power/configuration checks in Steps 26-29 and 30-31, command neutral from the configured FC, then return here and fit the arms. Do not close wings at Step 22 before this dependency and actual full-travel tests pass.

Seat the real mounting tabs against the actual rib. Use the servo supplied mounting hardware only after matching tab holes and screw/pilot dimensions; do not drive a guessed screw into a thin printed edge. The source servo envelope does not prove MG90S tab fit. If the tabs cannot be securely captured, hold this joint for measured fitting.

Fit HWL/HWR to their respective moving ailerons at the CAD contact. Abrade only the bond patch, clean and use the qualified adhesive through full cure. Horn pilot holes are nominal 2 mm for the pushrod, not servo mounting holes.

Trial one bicycle-spoke pushrod per wing with captive articulating ends. Measure its diameter, thread, arm hole and horn hole before cutting. The pictured 10 mm arm radius and straight rod are references, not a cut-length instruction. Leave all adjusters and the servo arm screw reachable.

Check before continuing: Servos and horns cannot shift under light control load; linkage moves without over-centre motion, rub or pin escape.

STEP 17

# Form and fit the fixed upright V-tail

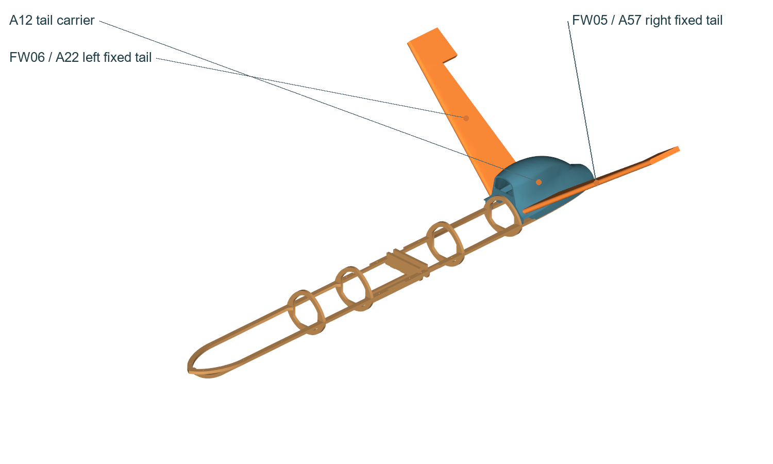
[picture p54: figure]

Upper: evolving body assembly. Lower: rear close-up shows both fixed tails seated symmetrically in the actual A12 carrier.

FW05 becomes the right fixed tail A57; FW06 becomes the left fixed tail A22. Each is one whole folded skin including its root collar. Match the source tail profile and trial the root against A12.

Precurve and fold progressively, keeping the outer paper intact. Remove or compress inner foam only where the fold and root need relief. Test on an offcut first. Dry-fit both fixed tails before bonding so their angles and trailing edges are symmetric.

Bond the tail skin and its A12 seating patch with a tested foam-safe adhesive that also suits the printed carrier where they contact. Support both tails at the CAD angles through full cure; do not force a warped tail into a socket.

Check before continuing: Tail roots seat in A12, both halves angle upward symmetrically and no paper is torn or core crushed.

STEP 18

# Laminate the moving tail controls and hinge them

Orange identifies parts added or checked now. All airframe shapes are placed CAD geometry.

FW12 right uses two 5 mm blanks to make A41; FW13 left uses two to make A60. Bond matching layers flat with the qualified foam adhesive. Keep supported through full cure, then finish the marked outline, trim allowance and rounded leading edge.

Hold each moving surface at neutral next to the fixed trailing edge. Apply reinforced tape to both faces and press the exposed tape together across the gap to form a flexible web. Keep the gap free from a hard glue bridge.

Trial movement roughly 15 degrees each way as a basic bench fit check, not a flight-qualified throw. The web must not peel, bind or allow fore-aft slop. Stop and remake a hinge that tears the paper or cannot move symmetrically.

Check before continuing: Both laminated controls are flat, retained by sound flexible webs and move freely in both directions.

STEP 19

# Fit the two tail servos and backed horns

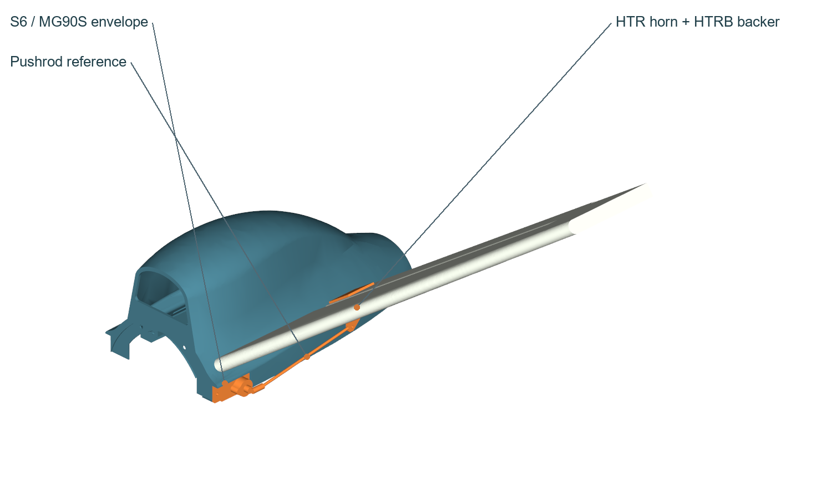
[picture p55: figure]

Right-side tail close-up; mirror the hardware for the left. Source servo envelope and schematic rod route require actual tab and linkage fitting.

S5 is the left tail MG90S and S6 the right. The source shaft targets are X-63.85/+63.85, Y411.10, Z6.215. They sit beside the original tail roots, with arms, centre screws and pushrod adjustments accessible.

Use the verified 5 V tester/neutral procedure in Step 16 before fitting the factory arms and retaining the arm screws. With no tester, leave arms off and return after the FC power/configuration checks; keep the skins open. Trial actual body/tabs, and use matching supplied hardware at sound mounting contact only. Hold a joint if the envelope does not securely seat the real unit.

Fit HTL/HTR horns to the left/right moving controls with HTLB/HTRB backing plates against the opposite foam face. The backers spread local load. Fit and cure the tested foam/print bond without crushing the core. Do not trust a horn glued to unsupported paper.

Use two more bicycle spokes as tail pushrods with measured, captive articulating ends. Cut only after full neutral and combined pitch/yaw movement has been tested. Keep rods clear of the carrier and motor wiring.

Check before continuing: Both tail servo mounts, horns and backers remain secure; every combined endpoint moves without rubbing or foam peel.

STEP 20

# Check the complete open structure

Orange identifies parts added or checked now. All airframe shapes are placed CAD geometry.
Put the body, both wings, fixed tails and controls together before any skin is glued closed. Confirm all wood laps are cured, printed root contacts are sound and rods and hinge pins are retained.

Move each control through full intended bench travel while supporting the airframe. Check rubbing, play, horn peel, servo buzz and an arm approaching over-centre. Correct the mechanical cause before limiting travel in software.

Run each wing servo cable to its root with enough slack for wing handling. Use smooth-edge tape/tie supports on fixed structure, avoiding hinges, pushrods and rod movement. Plan removable wing connectors and label S3 left / S4 right at both ends. Run tail cables forward along the frame, clear of the motor and driver path.

Leave an accessible route to the servo mounting and arm screws, connector separation points and tail adjusters. If you cannot service one of them after skinning, change the access plan now.

Check before continuing: Four controls move freely, every connector is labelled, and all restraints and service points can be inspected.

STEP 21

# Form the inner wing skins you already cut

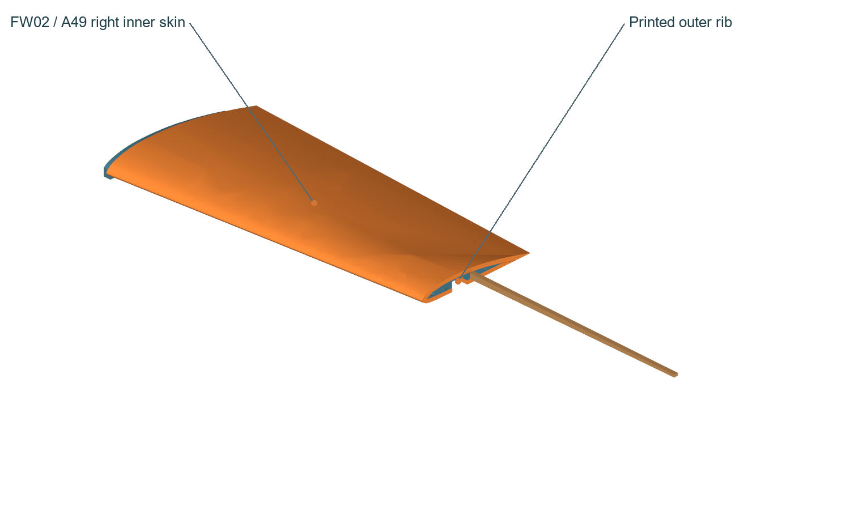
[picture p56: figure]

Orange identifies parts added or checked now. All airframe shapes are placed CAD geometry.

FW02 is the right inner skin (A49) and FW01 the left (A52). If each is already a whole skin, keep it intact. If supplied as ROOT/TIP cuts, butt the matching straight edges on a flat board, bond the core with foam-safe glue and tape across the outer paper. Cure the join before curving.

Mark the inside, leading edge and part ID from the cut map. Curve progressively over the actual inner wing frame; keep the outer paper continuous. Only relieve the inner core where a rib, rod or fold interferes. The source fold marks are hand references, not extra through-cuts.

Dry-fit the root, inner/middle ribs and rods together. Hold the airfoil without twisting it. Do not hide a broken spar or force a poor root fit under the skin.

Check before continuing: Each skin matches its side, forms without buckles and clears the whole rods and root without forcing.

STEP 22

# Dry-fit outer skins and keep access open

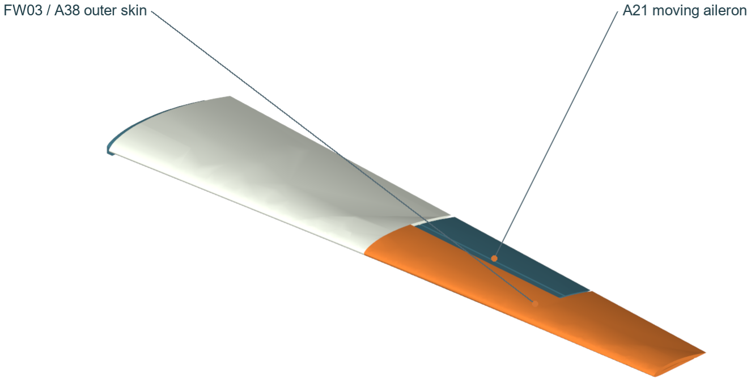
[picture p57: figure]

Actual outer skin shown in its final position, held temporarily for fit. Permanent closure waits for powered controls and supply checks.
FW03 is the right outer skin A38 and FW04 the left outer skin A27. Trial around the completed ribs, fixed rails, servos and controls. On the right, documented inner-foam relief is against A10_R and A53_R; mirror only the corresponding physical contact on the left.

Confirm rod/root retention, captive aileron pins, horn bond and servo mounting. Route the servo cable, test its connector and leave the servo arm accessible. Keep an inspectable/removable seam or opening at each servo rather than permanently burying it.

Hold the skins with removable tape now. Leave them unbonded until FC configuration, actual Vx/Vx2 loaded-servo movement, direction and failsafe tests pass. Final wing bonding is in Step 34; keep tape clear of the moving hinges.

Check before continuing: Both wings dry-fit symmetrically with smooth cable exits; all joints, servos and connectors remain accessible.

STEP 23

# Place and restrain the battery and electronics

Top view of actual frame with nominal device envelopes. Final positions follow real connector access, interference tests and measured balance.

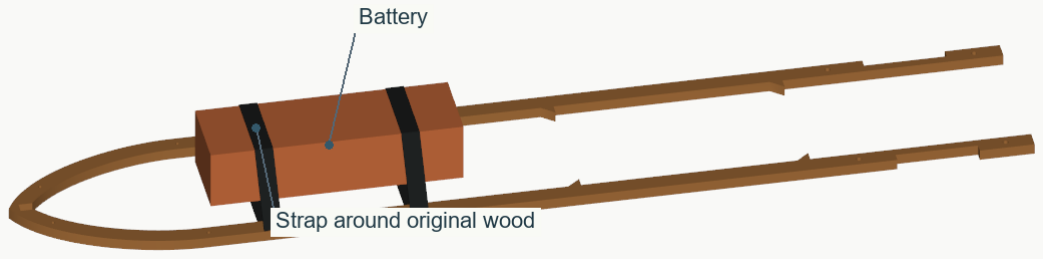
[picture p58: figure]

Start with the battery on sound A13 wood in the forward bay; the old centre target Y-260 is only a trial location. Use an insulating nonslip pad and two independent straps around the existing frame and battery. Round or pad sharp contact edges. Adhesive may locate the pad but must not be the only pack restraint.

Fit F405-WING V2 with known arrow/orientation on a suitable insulated vibration pad near the forward centre body. Leave USB, microSD and all plugs reachable. Place FS-iA10B nearby with separated antenna tips away from carbon and motor-current wiring.

Place the SiK AIR unit in the middle/aft body where its antenna and serial plug remain serviceable. Mount ReadytoSky 40A ESC aft on sound frame with ties/tape, cooling surface exposed and motor wires secured. Check its lead-length guidance before adding battery-wire length.

These drawn device boxes are nominal envelopes placed on real CAD, not exact device models or a fit certification. Trial the real leads, straps, cover and removal path. The old analysis already shows battery positions near Y-192 can collide with A34; do not force that position to chase a predicted CG.

Check before continuing: Battery cannot slip and can be removed unplugged; board USB/SD, receiver plug, radio and ESC remain accessible.

STEP 24

# Place GPS, pitot and airspeed tubes

Orange identifies parts added or checked now. All airframe shapes are placed CAD geometry.
Place the documented M9N-5883 GPS/compass with antenna face skyward in the upper nose region. Keep the compass at least 100 mm from power wiring, ESC, motor and ferrous hardware as the manufacturer recommends; centre-to-centre box spacing alone is insufficient. Verify the real clearance to leads.

Reuse the owned A59/N1 nose. With electronics and battery removed, offer up the actual pitot and mark a forward-facing passage that clears the shell, frame and nose removal path. Drill a controlled pilot and enlarge only for a snug tube/support fit. Do not copy a guessed CAD hole location.

Secure the pitot to sound support with tape/ties without covering sensing ports. Lead both silicone tubes to ASPD-4525 near the forward body; support gently, avoid kinks and leave the sensor ports reachable. Identify total/static ports from the actual sensor/manual.

The pressure sensor, GPS and radio must match their documented models before connector pin order is used. If a label differs, stop that connection and identify its exact manual; continue the other mechanical work.

Check before continuing: Nose removal does not pull the tubes; sensing holes remain open and compass separation is measured.

STEP 25

# Resolve and trial the rear motor interface

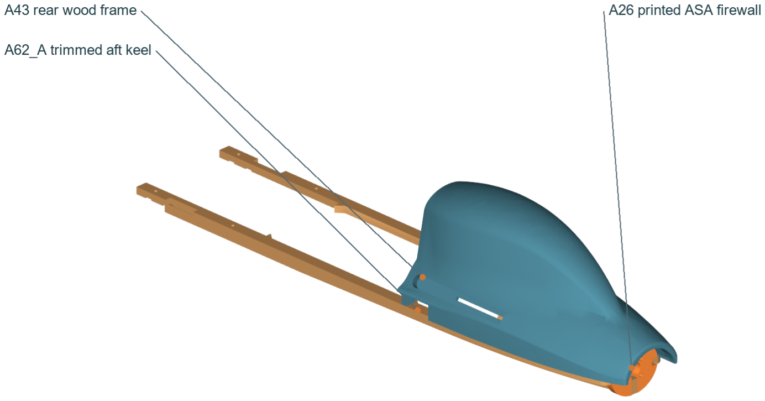
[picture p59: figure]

Corrected printed A26 on the actual rear frame. The footprint and slots are source geometry; material, layer strength, heat and actual fit still require physical proof.
The documented motor is EMAX ECO II 2807 1300KV. The official drawing specifies four M3 threads on a 19 mm pitch-circle diameter, giving 13.435 mm adjacent square spacing. The earlier guide and A26 literal 19 x 19 square are wrong for that drawing.

Set the cut wooden A26 aside. Use A26_ASA_6W_100RECT_NOSUP_L0p2_B8.stl: ASA, 6 walls, 100% rectilinear, 0.20 mm layers, no supports and 8 mm brim, broad forward face on the bed with motor face up. Keep the 6 mm source plate section. The filament/printer must support enclosed ASA printing; no PLA substitution is approved here.

The corrected printed flank seats are 6 mm deep, from Z0 down to Z-6, for the nominal 6 mm rear frame. The old wooden plate had 5 mm flank seats. Adding pitch-circle holes beside its old square holes would leave only about 0.735 mm ligament, so that old plate is not the replacement.

Remove all brim from the slots, keyhole and outer face, then check flatness after cooling. Dry-fit on A43/A62 with the real base, underside boss and propeller removed. Check holes, bell/wire clearance and driver access. Use a coupon-proved epoxy rated for ASA and wood at the actual frame contact, with the motor removed. Hold square through full cure; keep the shell open for the next check.

Check before continuing: Printed mount seats on the actual frame without force; actual motor base and holes match; ASA/wood bond sample passes before installation.

MOTOR DETAIL

# Motor fitting detail: keep the rest of the frame

Actual trimmed keel and corrected printed firewall. Only the aft projection is removed. Lower view shows the current source-derived ASA mounting face.

Trim only the A62_A aft projection: it currently ends at Y595.665. Mark the firewall aft plane Y582.650 and remove the 13.015 mm behind that plane. Support the keel and saw/file flush, keeping all material forward of the firewall and its joint. The CAD removes a demonstrated motor-envelope clash; check the real base and boss still seat.

A26 shaft centre remains X approximately 0 and Z-2.5. Four 3.2 mm clearance holes are equally spaced on diameter 19; their diagonal coordinates about the shaft are +/-6.718 mm in X/Z. Match the actual motor against the print before fastening.

Measure the screw/washer stack, head diameter and safe M3 thread depth. EMAX supplies M3x8/M3x10 but neither length is automatically approved. A screw must clamp the print without bottoming or reaching windings. Use compatible load-spreading heads/washers only after real driver, bell and slot clearance is verified; do not crush the polymer.

ASA has better heat resistance than PLA but is not a certified motor mount. Flat printing keeps the notch profile and torque path within continuous layers; prop thrust loads across layers and screws can cause creep. Qualify the cured frame joint, print layer adhesion, screw retention and the exact propulsion heating/vibration progressively before flight.

Check before continuing: If any interface still catches, provide a square-on photo of the mates with a ruler, actual wood thickness and safe M3 thread depth. Keep this stage open until proven.

STEP 26

# Connect high-current power with the prop off


Red traces show power routing on the real frame. Match the actual wire lengths and service loops; device boxes are nominal envelopes.
Keep the GenX RKI-4897 4S 5200 mAh pack disconnected. Its nominal voltage is 14.8 V and full voltage 16.8 V. Check the actual matching high-current main connector, positive and negative; the balance plug is for the charger, not the FC.

Connect the battery main positive/negative to F405-WING V2 BAT input with the verified connector and suitable rated wiring. Connect ESC thick positive/negative to the board PDB ESC power pads, following their actual labels. Connect the three motor phase wires to the ESC and restrain them clear of the bell and controls.

Connect ESC throttle signal to S1 and its control ground to G. The ReadytoSky family has a documented BEC despite some OPTO titles: inspect and meter your unit. If its red BEC wire is live, isolate and insulate that positive so it is not accidentally paralleled with onboard servo power.

Insulate every joint and support wires at frame ties without crushing insulation. With the battery still unplugged, check continuity, shorts, polarity and connector key orientation with a multimeter. Route high-current wiring away from compass, receiver antennas and sensor cables.

Check before continuing: Polarity and insulation pass; ESC BEC handling is verified; no motor wire can reach a moving part.

CONNECTIONS

# Power and motor connection map

From | To / net | Check
Battery main + / - | FC BAT + / GND | 4S 14.8 V nominal, 16.8 V full; connector polarity
FC/PDB ESC + / - | ESC DC + / - | Wire and pad rating; continuity; insulated joints
ESC three phase leads | Motor three phase leads | Prop off; secure away from rotating bell
FC S1 / G | ESC throttle signal / ground | Live ESC BEC positive isolated if onboard BEC used
FC Vx set to 5 V | S3 and S4 servo + rail | Measure before plugging in servos
FC Vx bridge to Vx2 | S5 / S6 servo + rail; S7 later | Vx2 is unpowered without bridge or separate supply
FC S3 / S4 / S5 / S6 | Each servo signal | Each servo also has +5 V and common GND

Check before continuing: Use actual board pad marks and actual keyed contacts; wire colour alone does not establish polarity.

STEP 27

# Connect servo power and receiver

Amber traces show fixed-frame harness routes from the four source servo locations to the FC. Leave labelled detachable connectors at wing roots. S7 is deferred.
Set the F405-WING V2 servo BEC Vx to 5 V for MG90S. Bridge Vx to Vx2 when using the onboard supply for the tail servos. Vx powers S3/S4; Vx2 powers S5/S6 and later S7. Measure both rails before connecting servo plugs.

Connect each servo lead signal, positive and ground to its matching output: S3 left aileron, S4 right aileron, S5 left V-tail, S6 right V-tail. Confirm the actual plug orientation. Keep S7 steering unplugged until gear is fitted after midsems.

Connect FS-iA10B servo-iBUS output signal to FC RX2, plus rated peripheral 5 V and common GND. Do not use the receiver SENS port. Label the wing connectors on both ends; protect their latch/release access.

Onboard Vx is rated 5 A continuous and 6 A peak; peripheral 5 V is rated 2 A total. Test actual simultaneous servo and accessory load before closing. Add up rated accessory consumption rather than assuming every 5 V connector has a separate supply.

Check before continuing: Each plug polarity and side is checked; Vx and Vx2 read 5 V; receiver servo-iBUS is on RX2.

STEP 28

# Connect sensors and the SiK air radio


Teal traces show sensor/receiver/radio routes on the real frame. Keep signal routes clear of high-current wiring; final plug orientation comes from the actual devices.
For documented M9N-5883, connect GPS TX to FC RX3 and GPS RX to FC TX3, plus rated 5 V/GND. Connect compass SDA to DA2 and SCL to CL2. TX crosses to RX; do not join TX to TX.

For documented ASPD-4525, connect its SDA to DA2 and SCL to CL2 on the same I2C2 bus, plus 5 V/GND. Its manufacturer GH order is 5V, SCL, SDA, GND. Check connector view/key on the actual device before fitting it; do not infer numbering from the aircraft picture.

Connect RKI-1980 SiK AIR TX to FC RX1 and AIR RX to FC TX1, with verified 5 V and GND. A standard 3DR GH-6 harness uses 1=5V, 2=FC TX1, 3=FC RX1, 4/5=CTS/RTS unused here, 6=GND; verify key orientation and continuity of your owned harness.

The black USB GROUND radio plugs into the computer, never into aircraft UART pads. Keep signal grounds common. Use a verified splitter/parallel harness for shared I2C; insulate unused contacts and support solder joints.

Check before continuing: Every labelled net reaches its intended device, no supply/signal contact is swapped, and I2C harness continuity passes.

CONNECTIONS

# Receiver, sensor and radio map

Device pin / net | F405-WING V2 pad | Notes
FS-iA10B servo-iBUS signal | RX2 | BRD_ALT_CONFIG=0; not SENS
Receiver + / GND | Peripheral 5V / GND | Check actual keyed harness
M9N GPS TX / RX | RX3 / TX3 | Cross serial directions
M9N compass SDA / SCL | DA2 / CL2 | I2C2 shared with airspeed
ASPD-4525 SDA / SCL | DA2 / CL2 | GH order 5V, SCL, SDA, GND
GPS and ASPD power / GND | Peripheral 5V / GND | 2 A total peripheral BEC budget
SiK AIR TX / RX | RX1 / TX1 | Cross serial; verify real harness
SiK AIR power / GND | Verified 5V / GND | GROUND USB unit stays at computer
Pitot total / static pressure | ASPD total / static ports | Two tubes; identify real ports; no kinks

Check before continuing: If any received device differs from the named model, identify its manual before connecting it.

## REAPER - COMPLETE ELECTRONICS CONNECTION MAP

One diagram for the owned parts. This is a functional net map, not a physical connector-position drawing.

### 1 HIGH-CURRENT POWER + MOTOR

GENX RKI-4897 4S

Main lead: positive + negative Yellow XT60-style plug: check mate White balance plug: charger only Remove pack for balance charging

MATEK F405-WING V2 - POWER

BAT input: 4S positive + negative
PDB ESC pads: ESC positive + negative 5V peripheral BEC: 2A total
Servo Vx BEC: 5V, 5A continuous

READYTOSKY 40A ESC

Thick DC + / - from FC/PDB
Thin throttle: signal + GND to S1/G BEC red: isolate IF live
Check actual unit despite OPTO title

EMAX ECO II 2807

Three motor phase wires from ESC Swap any two only if rotation wrong 9045 3-blade prop OFF during setup Current/thrust test before flight

BAT + / - | PDB + / - | 3 wires

### 2 FLIGHT-CONTROLLER SIGNALS + RATED 5V PERIPHERALS

SAME F405-WING V2 - I/O

S1/G : ESC control signal + ground RX2 : receiver servo-iBUS input TX3/RX3 : GPS serial UART3 DA2/CL2 : shared I2C2 bus
TX1/RX1 : SiK air telemetry UART1 S3-S7 : servo PWM outputs
Vx -> Vx2 bridge for S5-S7 power Read actual V2 board pad markings

FLYSKY FS-iA10B RX

servo-iBUS signal -> FC RX2 FC peripheral 5V -> RX +
FC GND -> RX GND; not SENS

RKI-1980 SERIAL AIR RADIO

AIR TX -> FC RX1; AIR RX <- FC TX1 standard GH-6: 1=5V, 2=FC TX1
3=FC RX1, 4/5=CTS/RTS unused 6=GND; verify keyed cable

MATEK M9N-5883 GPS + COMPASS

GPS TX -> FC RX3; GPS RX <- FC TX3 Compass DA -> DA2; CL -> CL2
FC peripheral 5V + GND
Keep compass away from current wires

MATEK ASPD-4525 AIRSPEED

SDA -> DA2; SCL -> CL2 (shared I2C2) JST-GH order: 5V, SCL, SDA, GND
Two silicone pressure tubes -> pitot

iBUS

UART1

GPS + I2C

I2C2

BLACK USB GROUND RADIO

USB -> laptop; radio link to AIR unit

radio / RF link

PITOT AT NOSE

Two tubes to ASPD; prove positive reading

### 2 air tubes

### 3 FIVE MG90S SERVOS - EACH LEAD HAS SIGNAL, +5V AND GND

Use Vx 5V for S3/S4. Bridge Vx to Vx2 for S5/S6/S7 when using the onboard servo BEC.

S3 LEFT AILERON

PWM=S3; Vx 5V; GND

S4 RIGHT AILERON

PWM=S4; Vx 5V; GND

S5 LEFT V-TAIL

PWM=S5; Vx2 5V; GND

S6 RIGHT V-TAIL

PWM=S6; Vx2 5V; GND

S7 NOSE STEERING

PWM=S7; Vx2; GND; gear later

BEFORE POWER: | Propeller off; verify polarity and plug/key order. Isolate ESC BEC red only if live.
BEFORE FLIGHT: | Prove loaded Vx/Vx2, controls/failsafe, pitot, motor current/thrust and CG.
Solid lines = electrical route; purple dashed = radio link; gray dashed = air tubes/optional S7. | Functional connections - check actual keyed contacts

STEP 29

# Power carefully and prove the open installation

Orange identifies parts added or checked now. All airframe shapes are placed CAD geometry.
Propeller removed, transmitter on with throttle low: first power the isolated board by USB for inspection. After continuity/polarity checks, test the flight-power wiring with an appropriate current-limited source. Do not exceed any input range.

Measure Vx/Vx2 and peripheral 5 V. Connect accessories one group at a time, watching for heat, wrong polarity and unusual current. Leave servo movement for the following firmware/output checks; then test all four simultaneously on the actual Vx/Vx2 rails under a representative light control load before final skin closure.

Save the observed voltages, load current and any fault. Disconnect battery power before swapping a plug. Correct a mechanical bind before increasing power or adjusting endpoints.

Check nose and cover removal with all harnesses in place. Mark every detachable connector and leave a short service loop without a loose coil near the motor. Take clear photos of the complete open installation for later service.

Check before continuing: Polarity and idle rails pass; no heat or resets; powered servo-load proof stays open until after output configuration.

STEP 30

# Install firmware and save the starting settings


Aircraft orientation reference for checking the ground-station attitude display; software values require readback on the real controller.
With the propeller removed, connect the F405-WING V2 to Mission Planner over USB. In Initial Setup > Install Firmware choose Plane and the exact MatekF405-Wing target supported for the V2 board. Follow the current board instructions; do not flash a similarly named target by appearance.

Connect, record firmware version and board identity, then save a parameter file in Config/Tuning > Full Parameter List before changes. In the attitude display move the airframe by hand: nose down/up and right/left roll must match the display. Set board/compass orientation to the real installation.

Set BRD_ALT_CONFIG=0 for iBUS on RX2 and check channel bars in Initial Setup > Radio Calibration. Turn transmitter V-tail mixing off so the controller owns the mix. Reboot when a parameter instruction requires it, then read the value back.

Menu wording can vary by ground-station version. This procedure is an instruction for your hardware; no aircraft was connected or firmware flashed while creating this guide.

Check before continuing: Correct target/version and baseline file recorded; attitude and every receiver channel respond in the correct sense.

CONFIGURATION

# Assign the actual outputs explicitly

In Full Parameter List set and write the output functions below. Read them back after restart. Output IDs do not establish correct movement; Step 33 proves the directions.

Do not import a ready-to-fly file. Keep S7 steering deferred until measured gear fitting. Start with conservative neutral/endpoints established from free mechanical travel; flight throws require experienced pilot acceptance.

Parameter | Starting value | Actual device
SERVO1_FUNCTION | 70 | Throttle / ESC S1
SERVO3_FUNCTION | 4 | Left aileron S3
SERVO4_FUNCTION | 4 | Right aileron S4
SERVO5_FUNCTION | 79 | Left V-tail S5
SERVO6_FUNCTION | 80 | Right V-tail S6
SERVO7_FUNCTION | 26 later | GroundSteering only after gear fitted
BRD_ALT_CONFIG | 0 | iBUS RX2
SERIAL3_PROTOCOL | 5 if required | GPS on UART3
BATT_VOLT_MULT / BATT_AMP_PERVLT | 11.0 / 66.7 for V2 | Calibrate readings against meter
ARSPD_TYPE / ARSPD_BUS | 1 / 1 for ASPD-4525 | Verify actual firmware bus mapping

Check before continuing: Write, restart as required and read back; final reversal, endpoints and failsafe still need physical tests.

STEP 31

# Calibrate radio, attitude, compass and airspeed


Orange identifies parts added or checked now. All airframe shapes are placed CAD geometry.
Propeller off: follow Radio Calibration and Accelerometer Calibration in Initial Setup. Set known board and compass orientations. Recheck displayed roll/pitch and save changed parameters. Check SiK UART1 and the air/ground pair settings before claiming telemetry works.

Take the aircraft outdoors away from metal and power interference for compass calibration and GPS lock. Check live satellite/position data; keep the compass at its final mounted location. Recheck interference after the power harness is fixed.

Zero ASPD-4525 in still air and inspect both pressure tubes. Use the current ArduPilot airspeed setup for the actual firmware; ARSPD_TUBE_ORDER=2 is auto only if supported. Gently direct airflow toward the pitot and confirm a positive reading. Do not blow strongly into the sensor or assume swapped ports are acceptable.

Compare battery voltage/current with a suitable measured reference. The V2 starting scales are 11.0 and 66.7 A/V, not the older V1 current scale. A displayed sensible number alone is not a calibration.

Check before continuing: Radio endpoints, attitude signs, compass orientation, GNSS and positive airspeed response are recorded; voltage/current agree with measurement.

CONFIGURATION

# Pair the SiK radios and prove telemetry

The AIR unit in the frame sends telemetry; the GROUND USB unit remains at the computer. Teal lines show actual-frame harness routes.
Fit the correct antennas to both radios before powering them. With the ground station disconnected from the vehicle, choose the GROUND USB radio COM port at 57600 baud. In Mission Planner open Initial Setup > Optional Hardware > SiK Radio and Load Settings for local and remote units.

Inspect the pair before changing good defaults. Net ID and required Air Speed/ECC settings must agree. If they do not, use Copy Required Items to Remote and Save Settings per the current SiK procedure. AIR serial baud must match FC UART1; GROUND serial baud must match the computer. Do not invent radio transmit power or range.

On the F405 set SERIAL1_PROTOCOL=1 for MAVLink1, or 2 only if the radio firmware supports MAVLink2; SERIAL1_BAUD=57 means 57600. Write, restart as required and read back the values. These settings apply to TX1/RX1, not the GPS UART.

A solid green SiK link LED indicates a paired link; blinking indicates searching. Select the GROUND COM at its matching baud and Connect. Check live heartbeat/parameters and tilt the aircraft to see Flight Data attitude update over radio. If it fails, disconnect flight power before checking crossed TX/RX, supply/ground, baud and pair settings. Keep USB available for recovery.

Check before continuing: Actual radio-link connection and live attitude/parameters pass; a lit power LED alone does not prove telemetry.

STEP 32
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

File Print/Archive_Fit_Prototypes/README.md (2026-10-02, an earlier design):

Earlier A26 and A44 printed-fit geometry/settings are archived references. The current R5G job uses plywood A26 and reinforced plywood A44_L/R. These files are not current manufacturing instructions and do not establish flight-qualified PLA mounts.

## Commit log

2026-09-19 Add revised MQ9 fabrication package and build guides
    [A01.dxf, A01_manufacturing.step, A01_opposite_wing_manufacturing.step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]
2026-09-19 Simplify team guides and publish a focused manufacturing handoff
    [Complete_Parts_and_Materials.csv, Decision_Record.tsv, F01_triangles.csv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]
2026-09-20 Integrate internal electronics and publish Revision 2 build package
    [A01_opposite_wing_manufacturing.step, A02_Main_gear_formed_and_drilled.step, A02_Main_gear_front_template.dxf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]
2026-09-20 Expand flight calculations and clarify structural tail print qualification
2026-09-21 Regenerate nose shell STL for broad slicer compatibility
    [A01_opposite_wing_manufacturing.step, A05_opposite_wing_manufacturing.step, A07_opposite_wing_manufacturing.step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]
2026-09-21 Reduce tail shell mesh density for viewer compatibility
    [A01_opposite_wing_manufacturing.step, A05_opposite_wing_manufacturing.step, A07_opposite_wing_manufacturing.step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]
2026-09-22 Release simplified N1 nose and mark Rev2 aircraft redesign pending
    [A59_Nose_N1_mm.stl, A59_Nose_N1_positioned.step]
2026-09-23 Rebuild simple Reaper prototype manufacturing package
    [A01.dxf, A01_manufacturing.step, A01_opposite_wing_manufacturing.step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]
2026-09-23 Replace build report with illustrated workshop guide
    [Guide_Page_Map.csv, Guide_Parts_Checklist.csv]
2026-09-23 Release corrected single-sheet plywood cut revision with fit coupons
    [FMF.dxf, FMF.step, FMT.dxf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]
2026-09-23 Integrate REV3 motor fix, wood-shaded guide and buildability audit
    [Auxiliary_Test_Pieces.csv, Cut_Patterns.csv, FMF.dxf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]
2026-09-23 Release REV4 plywood panel build with foam controls and illustrated guide
    [AL.dxf, AL.step, AL.stl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]
2026-09-23 Release original-style R5 prototype fabrication package
    [A01_L.dxf, A01_L.step, A01_R.dxf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]
2026-09-24 Release clean R5C fabrication panels and wiring guide
    [A01_L.dxf, A01_R.dxf, A04.dxf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]
2026-09-24 Publish R5D complete wiring foldout and guide
2026-09-25 Fit foam cutting panels to 600 x 400 mm bed
    [Foam_Manifest.csv, PART_TO_PANEL.csv, Parts.csv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]
2026-09-30 Correct printed rear mount and ribs; add illustrated R5F assembly handoff
    [A26.step, A26_ASA_6W_100RECT_NOSUP_L0p2_B8.stl, A44_L.step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]
2026-10-01 Remove verification clutter and clarify current Reaper files
    [Beginner_Guide_assembly_map.csv, Endurance_Scenarios.csv, MOTOR_MOUNT_R5B_CHECK.json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]
2026-10-02 Correct R5G plywood fits and publish complete assembly guide
    Update A01, A18, A26 and reinforced A44 interfaces; incorporate the aft-keel cut length and retain exact source mating datums. Publish the reviewed 74-page guide and four unchanged-geometry cutting batches, update current manifests and archive superseded manufacture options. Digital readbacks, quantity/layout checks, all-page review and installed-file verification pass; physical fit, hardware engagement, loads and flight acceptance remain pending.
    [A01_L.dxf, A01_L.step, A01_R.dxf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]
